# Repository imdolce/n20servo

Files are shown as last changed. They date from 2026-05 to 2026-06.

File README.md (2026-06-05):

<div align="center">
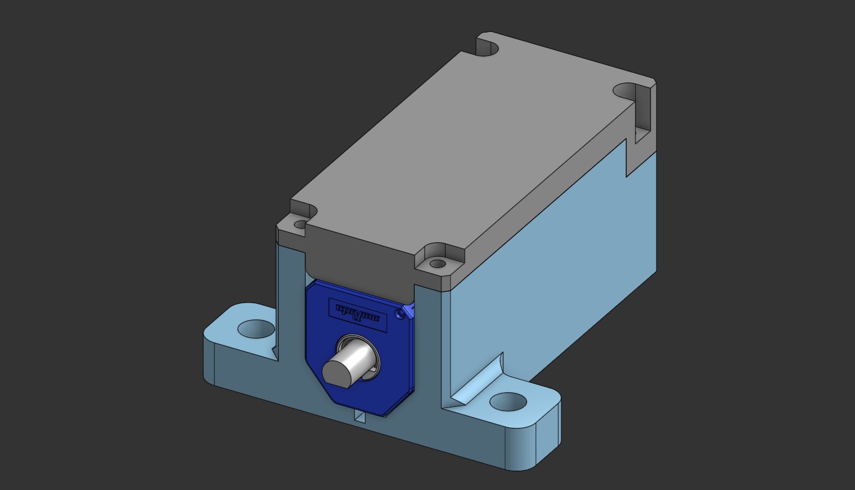
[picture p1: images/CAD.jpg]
N20 Servo CAD Assembly
  
  <h1>N20 Servo</h1>
  <p><strong>A CH32V003-powered small size closed-loop actuator</strong></p>
  
  <p>
    
    
    
    
  </p>
</div>

<hr />

<h2>Table of Contents</h2>
<ul>
  <li><a href="#introduction">1. Introduction</a></li>
  <li><a href="#credits">2. Credits</a></li>
  <li><a href="#technical-specs">3. Technical Specifications</a></li>
  <li><a href="#pcb-and-hardware-revisions">4. PCB & Hardware Revisions</a></li>
  <li><a href="#cad-and-mechanical-design">5. CAD & Mechanical Design</a></li>
  <li><a href="#firmware-and-platformio-environments">6. Firmware & PlatformIO Environments</a></li>
  <li><a href="#additional-tools">7. Additional Tools</a></li>
  <li><a href="#changelog">8. Changelog</a></li>
</ul>

<hr />

<h2 id="introduction">1. Introduction</h2>
<p>
  The <strong>N20 Servo</strong> is an affordable, high-performance(?) closed-loop actuator system built around the WCH CH32V003 RISC-V 32-bit microcontroller. The project was created from my dissatisfaction of the SG90 servo performance: lots of backlash and weak torque, and the failed attempt when trying and modify the servo with the DIY solution (link in Credits) but found it rather hard to properly install the very thin metal wiper and secure the potentiometer body onto the metal surface of the motor. Therefore, I set my goal on creating a better alternative.
</p>
<p>
  This project contains the firmware, CAD assemblies, PCB views, and debugging utilities required to build, test, and tune.
  <br>
  If there's anything wrong, you can raise an issue and let me know. Thank you for your help.
</p>

<hr />

<h2 id="credits">2. Credits</h2>
<p>
  This project is designed, developed, and maintained by: imdolce (aka dolce_st, hovietkien49).
</p>

> [!IMPORTANT]
> Code base development is assisted by OpenAI Codex. On my side, I try to read and comprehend the functions used on this chip or the whole CH32 family in general, as it is my first time working with this chip.

<p>
  Other sources and ideas:
</p>
<ul>
<li>DIY Servo Modding Guide: <a href="https://www.youtube.com/watch?v=6JWuUFiOJBk">How to convert an N20 gear motor into a servo using SG90 parts</a> — by JANIUL HAQ</li>

<li>Angle Sensor Adapter: <a href="https://github.com/jkugalde/N20-Servo-Module">N20-Servo-Module (3D print + N20 motor + angle sensor = servo motor)</a> — by jkugalde</li>

<li>N20 DC Motor CAD Model: <a href="https://grabcad.com/library/n20-dc-gear-motor-1">N20 DC Gear Motor | GrabCAD Library</a> — by RamBros 3D</li>

<li>SG90 CAD Model: <a href="https://grabcad.com/library/sg90-micro-servo-9g-tower-pro-1">SG90 Micro Servo 9g | GrabCAD Library</a> — by Mattheus Frasson</li>

</ul>

<hr />

<h2 id="technical-specs">3. Technical Specifications</h2>
<p>The following table outlines the hardware and software specifications of the N20 Servo:</p>

<table border="1" cellpadding="8" cellspacing="0" style="border-collapse: collapse; width: 100%; border-color: #ddd;">
  <thead>
    <tr style="background-color: #f2f2f2;">
      <th align="left">Parameter</th>
      <th align="left">Specification</th>
      <th align="left">Notes</th>
    </tr>
  </thead>
  <tbody>
    <tr>
      <td><strong>Microcontroller</strong></td>
      <td>WCH CH32V003J4M6 (RISC-V 32-bit Core @ 48 MHz)</td>
      <td>Dirt cheap 5 cents MCU.</td>
    </tr>
    <tr>
      <td><strong>Operating voltage</strong></td>
      <td>5V</td>
      <td>Shared power bus with motor driver.</td>
    </tr>
    <tr>
      <td><strong>Actuator</strong></td>
      <td>N20 Geared DC Motor</td>
      <td>High torque, compact size.</td>
    </tr>
    <tr>
      <td><strong>H-bridge chip</strong></td>
      <td>RZ78xx, SA8301, DRV8210, DRV8837</td>
      <td>RZ78xx driver series include: RZ7888, RZ7889, RZ7899. Currently the RZ7888 and SA8301 are used because it's cheap.</td>
    </tr>
    <tr>
      <td><strong>H-Bridge Output</strong></td>
      <td>Dual-PWM control on <code>PC1</code> and <code>PC2</code></td>
      <td>Drives motor direction and speed using TIM2.</td>
    </tr>
    <tr>
      <td><strong>PWM Frequency</strong></td>
      <td>2.0 kHz</td>
      <td>Adjustable via <code>MOTOR_PWM_HZ</code> in config.</td>
    </tr>
    <tr>
      <td><strong>Position Feedback</strong></td>
      <td>SV01A103AEA01R00 10K (or similar clones) angle position detector (Wiper input pin <code>PA2</code>)</td>
      <td>Read via ADC1 Channel 0, 10-bit resolution..</td>
    </tr>
    <tr>
      <td><strong>Traverse range</strong></td>
      <td>Up to 330° (-165° to +165° symmetrical) mechanical travel</td>
      <td>To make the servo safely accomodate within the wiper track of the angle detector, the traverse angle is limited to 320° (-160° to +160° symmetrical).</td>
    </tr>
    <tr>
      <td><strong>Input Signal</strong></td>
      <td>50 Hz RC Servo PWM, <code>PC4</code></td>
      <td>Captured via TIM1 Channel 4 (1000µs to 2000µs, 0° angle at 1500µs).</td>
    </tr>
    <tr>
      <td><strong>Polling rate</strong></td>
      <td>500 Hz (2 ms)</td>
      <td>Position feedback and control loop.</td>
    </tr>
    <tr>
      <td><strong>Telemetry UART</strong></td>
      <td>921600 baud on <code>PD5</code> (UART1 Remap 2 TX)</td>
      <td>CSV telemetry output for live tuning.</td>
    </tr>
  </tbody>
</table>

<hr />

<h2 id="pcb-and-hardware-revisions">4. PCB & Hardware Revisions</h2>

> [!TIP]
> You can view & get the PCB schematic and designs in this repository, or visit my post on OSHWLAB (coming soon).

> [!IMPORTANT]
> It is not recommended to order PCB of the initial version <code>1D2 (1Д2)</code>, as it requires good soldering skill to install components on both sides and wiring up the angle detector with bodge wires. The <code>1D3 (1Д3)</code> version aims to resolve both issues. More details will be added as soon as I can get my hands on the new <code>1Д3</code> PCB. 

<h3> 1. Initial version  <code>1D2 (1Д2)</code></h3>
<p>The electronics are designed to fit directly on top of the N20 motor. The enclosure is designed specifically for the first revision <code>1Д2</code> </p>

<table border="1" cellpadding="8" cellspacing="0" style="border-collapse: collapse; width: 100%; border-color: #ddd;">
  <thead>
    <tr style="background-color: #f2f2f2;">
      <th align="left" style="width: 25%;">View</th>
      <th align="center" style="width: 45%;">Imagew</th>
      <th align="left" style="width: 30%;">Description</th>
    </tr>
  </thead>
  <tbody>
    <tr>
      <td><strong>PCB View</strong></td>
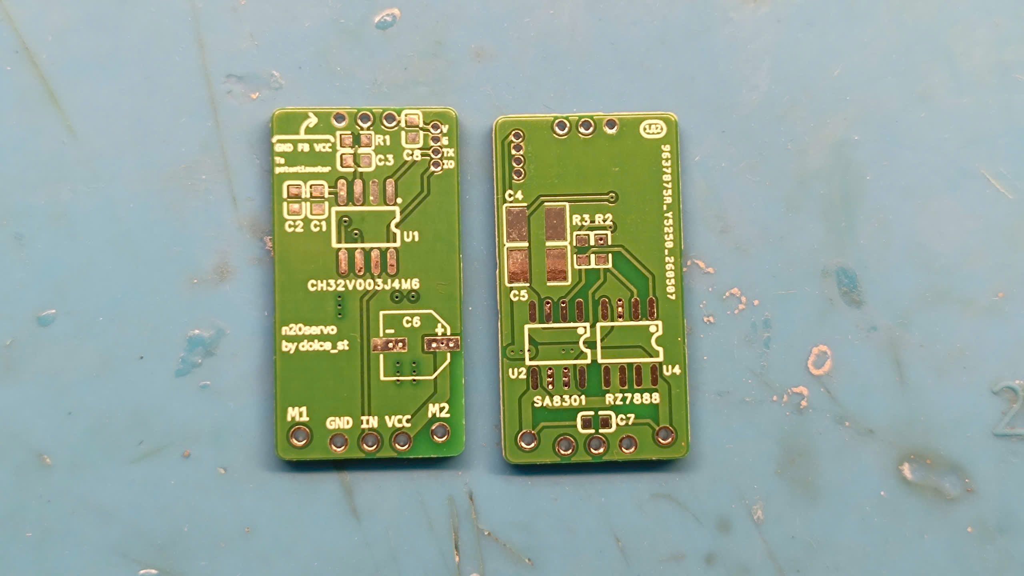
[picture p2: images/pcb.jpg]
      <td align="center"></td>
      <td>Bare PCB appearance, top and bottom view.</td>
    </tr>
    <tr>
      <td><strong>Top populated view</strong></td>
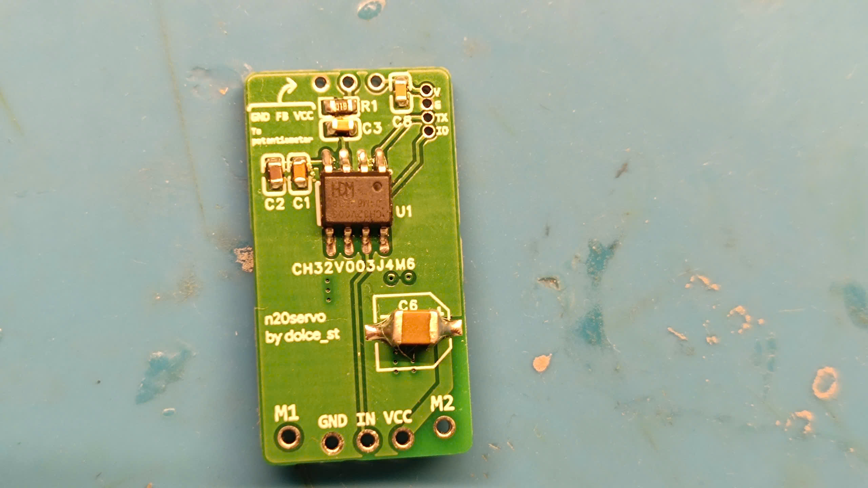
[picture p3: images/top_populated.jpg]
Top Populated PCB
      <td align="center"></td>
      <td>Fully populated top view of the PCB.</td>
    </tr>
    <tr>
      <td><strong>Bottom populated view</strong></td>
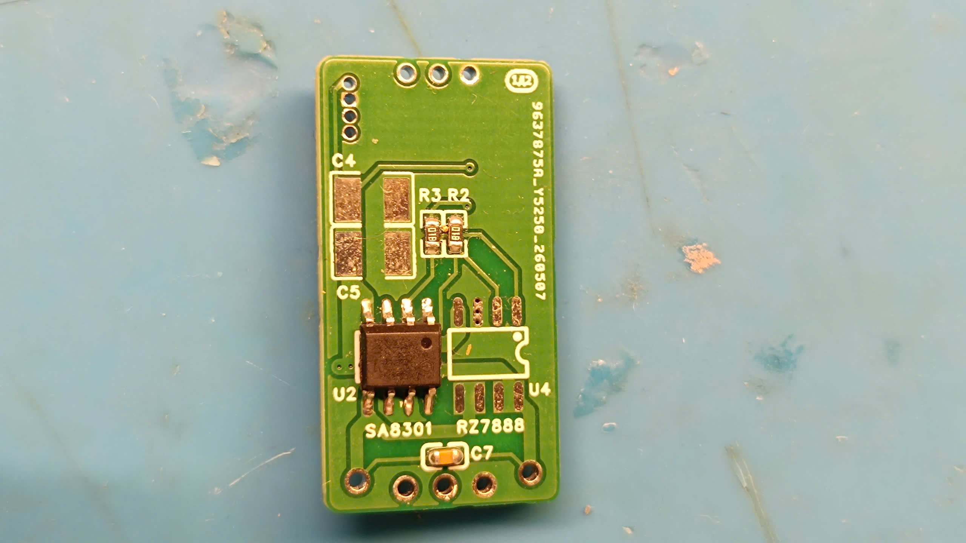
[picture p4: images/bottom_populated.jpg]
Bottom Populated PCB
      <td align="center"></td>
      <td>Partially populated bottom view of the PCB, bottom 2 22uF capacitors are removed due to their interference with the motor below. </td>
    </tr>
    <tr>
      <td><strong>Angle sensor and adapter collet</strong></td>
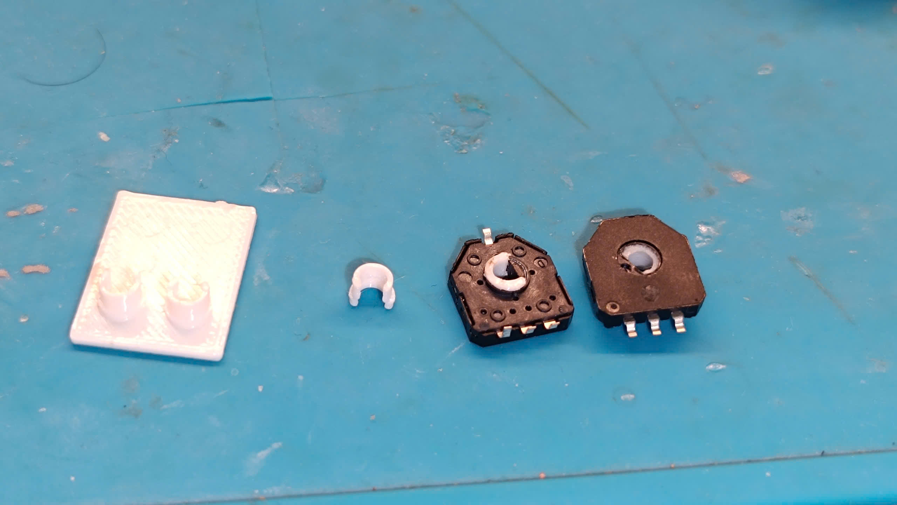
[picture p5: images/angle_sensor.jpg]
Angle Sensor
      <td align="center"></td>
      <td>Top and bottom view of the angle sensor, with the adapter collet installed, the standalone collet (second to the left side) the 3D printed custom fixture to easily print the adapter collets (white rectangle on the left side)</td>
    </tr>
    <tr>
      <td><strong>Test setup</strong></td>
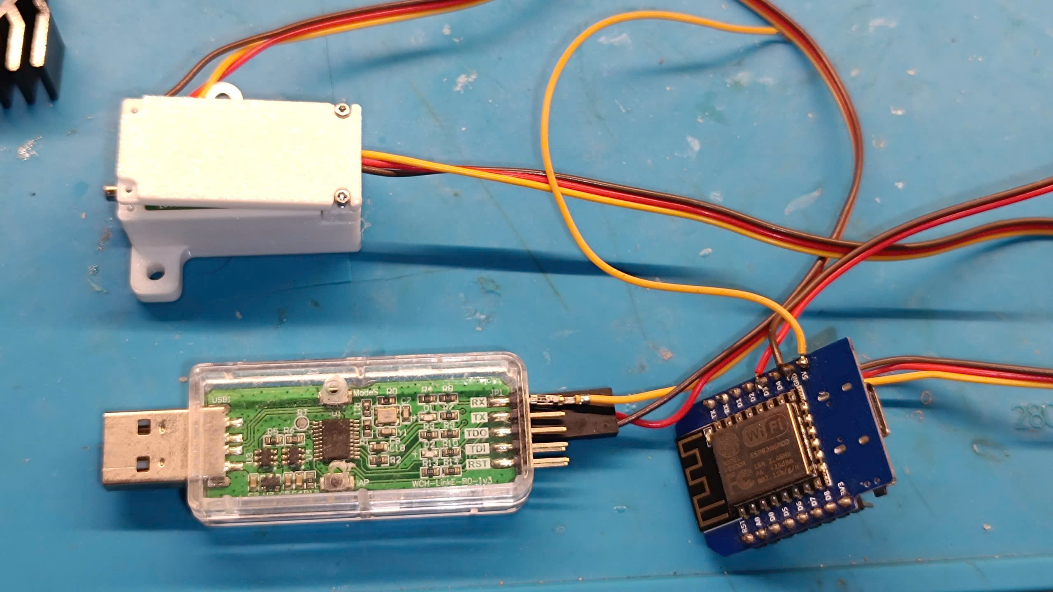
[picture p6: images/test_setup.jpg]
Test Setup
      <td align="center"></td>
      <td>Consists of: Partially assembled N20 Servo assembly (to make space for the Outcoming UART TX telemetry), WEMOS D1 Mini for PWM output, WCH-LinkE for UART telemtry reading and MCU programming.</td>
    </tr>
  </tbody>
</table>

<h3> 2. Second version  <code>1D3 (1Д3)</code></h3>
<p> In this new version, it aims to resolve the difficulty of populating the PCB and wiring the angle detector. Currently I have not tested the design myself, so documentation is limited. There are 5 different PCB designs, <code>1Д3-1/2/3/4</code> incorporates 4 different designs of 4 different motor drivers, it was made to avoid ordering multiple PCB revisions. The remaining 4 designs <code>1Д3-1</code>, <code>1Д3-2</code>, <code>1Д3-3</code>, <code>1Д3-4</code> are standalone boards, using the <code>SA8301</code>, <code>RZ7888</code>, <code>DRV8210DRLR</code>, <code>DRV8837DSGR</code> respectively to each design.</p> 

<table border="1" cellpadding="8" cellspacing="0" style="border-collapse: collapse; width: 100%; border-color: #ddd;">
  <thead>
    <tr style="background-color: #f2f2f2;">
      <th align="left" style="width: 25%;">View</th>
      <th align="center" style="width: 45%;">Image</th>
      <th align="left" style="width: 30%;">Description</th>
    </tr>
  </thead>
  <tbody>
    <tr>
      <td><strong>PCB View</strong></td>
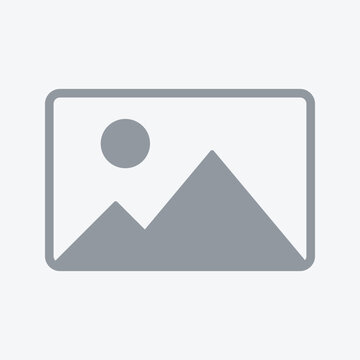
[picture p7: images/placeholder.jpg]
      <td align="center"></td>
      <td>Coming soon.</td>
    </tr>
    <tr>
      <td><strong>Top populated view</strong></td>
      <td align="center">Top Populated PCB</td>
      <td>Coming soon.</td>
    </tr>
    <tr>
      <td><strong>Bottom populated view</strong></td>
      <td align="center">Bottom Populated PCB</td>
      <td>Coming soon.</td>
    </tr>
  </tbody>
</table>

<hr />

<h2 id="cad-and-mechanical-design">5. CAD & Mechanical Design</h2>
<p>
  The enclosure is designed using Onshape. The link is included here: <a href="https://cad.onshape.com/documents/3d875b828e8759d6e6ceaa1a/w/557cd3ef9bc182fa57785d1d/e/bd1feb28422a2b0780a86111">CAD Design </a>
</p>

> [!IMPORTANT]
> Use 4x M1.4x6 Self-tap SHCS and a 1.3mm Allen key or T4 Torx screwdriver bit to close and secure the top cover. The same screw size will persist across all future releases.

<div align="center">
  <table border="0" cellpadding="4" cellspacing="0" style="border-collapse: collapse; margin: auto;">
    <tr>
      <td align="center" style="padding: 10px;">
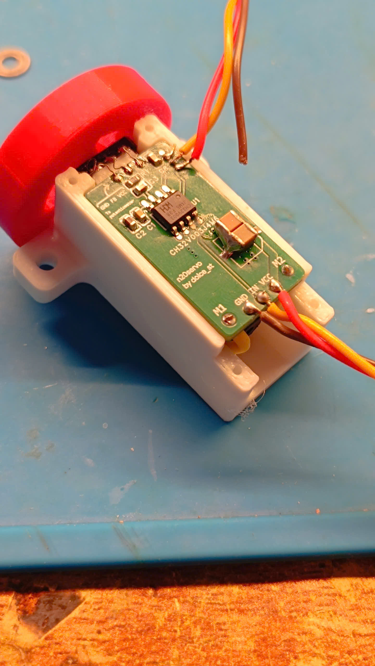
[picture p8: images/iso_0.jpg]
Isometric View
        <br/>
        <em>Isometric View</em>
      </td>
      <td align="center" style="padding: 10px;">
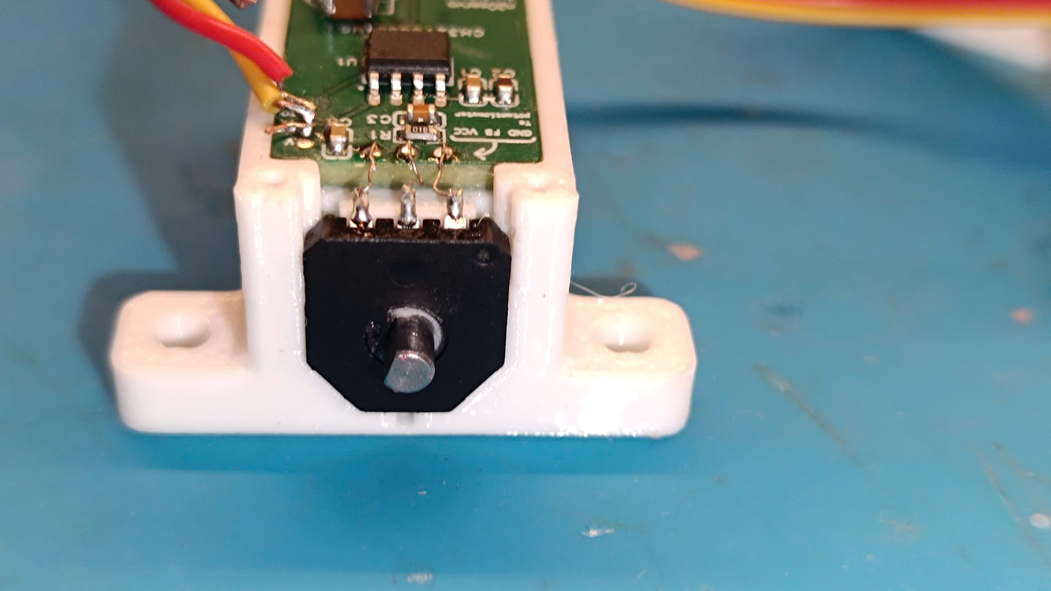
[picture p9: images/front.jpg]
Front View
        <br/>
        <em>Front View</em>
      </td>
    </tr>
    <tr>
      <td align="center" style="padding: 10px;">
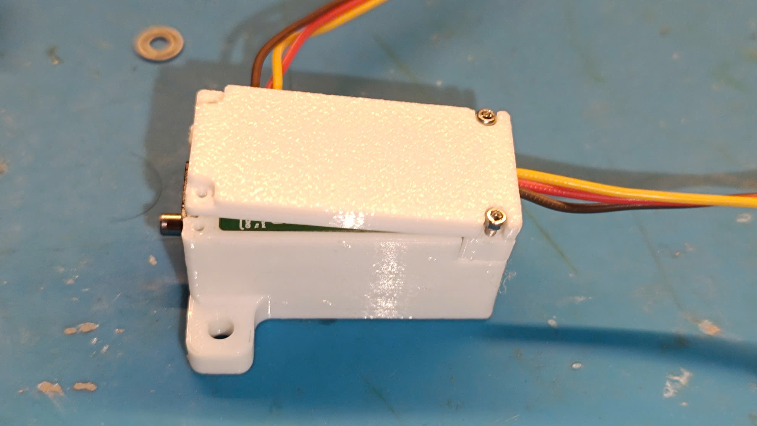
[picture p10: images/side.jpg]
Side View
        <br/>
        <em>Side View</em>
      </td>
      <td align="center" style="padding: 10px;">
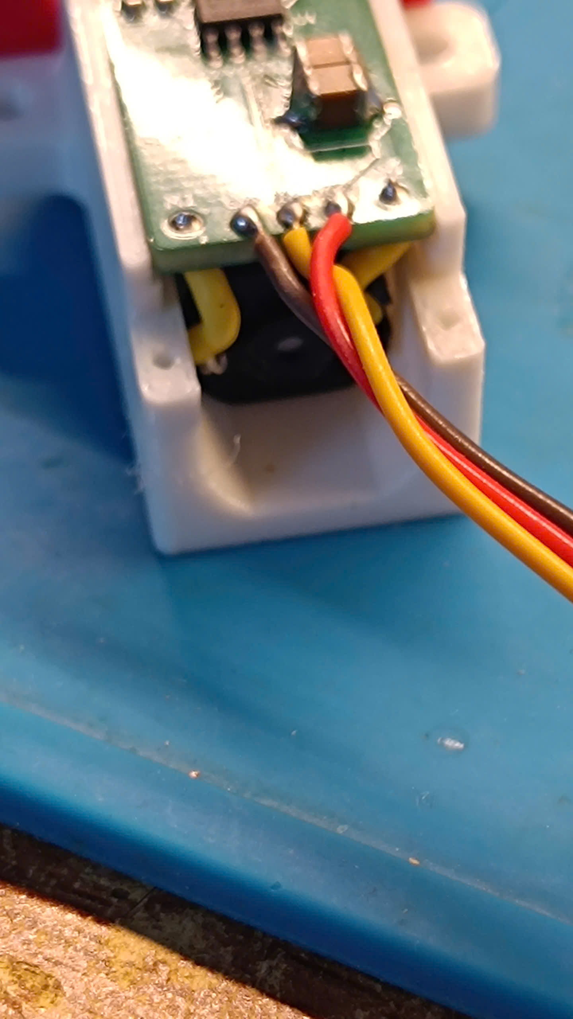
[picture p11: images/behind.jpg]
Rear View
        <br/>
        <em>Rear View</em>
      </td>
    </tr>
    <tr>
      <td align="center" colspan="2" style="padding: 10px;">
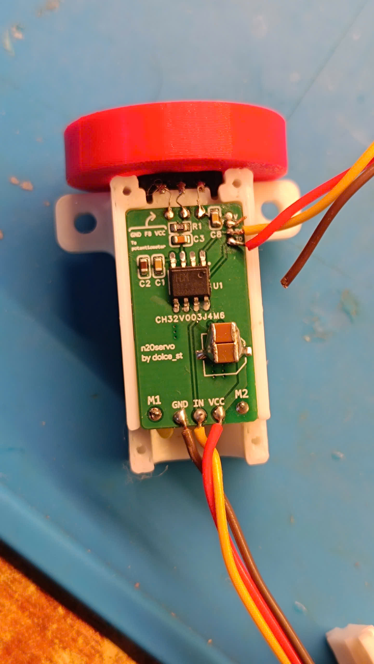
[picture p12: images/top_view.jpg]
Top View
        <br/>
        <em>Top Down View</em>
      </td>
    </tr>
  </table>
</div>

<hr />

<h2 id="firmware-and-platformio-environments">6. Firmware & PlatformIO Environments</h2>
<p>
  The firmware is written in C, using WCH Standard Peripheral Library (StdPeriphLib) <code>aka noneos-sdk</code>. The project is managed using <a href="https://platformio.org/">PlatformIO</a>.
</p>

<h3>Build & Uploading</h3>
<p>To compile and upload the default firmware environment using a WCH-LinkE programmer, run:</p>
<pre><code>platformio run -e genericCH32V003J4M6_servo_control -t upload</code></pre>
<p>Or click the Upload button</p>

<h3>PlatformIO Environments</h3>
<p>The environment for this project is defined in <code>platformio.ini</code>:</p>

<table border="1" cellpadding="8" cellspacing="0" style="border-collapse: collapse; width: 100%; border-color: #ddd;">
  <thead>
    <tr style="background-color: #f2f2f2;">
      <th align="left">Environment Name</th>
      <th align="left">Description</th>
      <th align="left">Build Configurations</th>
    </tr>
  </thead>
  <tbody>
    <tr>
      <td><code>genericCH32V003J4M6_servo_control</code></td>
      <td><strong>Production Closed-Loop Servo</strong>: Primary operational environment. Telemetry output is disabled to prevent UART TX blocks and ensure minimum control loop jitter.</td>
      <td><code>TEST_MODE_SERVO_CONTROL</code><br/><code>SERVO_CONTROL_TELEMETRY_ENABLE=0</code></td>
    </tr>
    <tr>
      <td><code>genericCH32V003J4M6_servo_control_debug</code></td>
      <td><strong>Debug Closed-Loop Servo</strong>: Enables high-speed CSV telemetry output via UART for visualization and tuning.</td>
      <td><code>TEST_MODE_SERVO_CONTROL</code><br/><code>SERVO_CONTROL_TELEMETRY_ENABLE=1</code></td>
    </tr>
    <tr>
      <td><code>genericCH32V003J4M6</code></td>
      <td><strong>Motor Sweep Test</strong>: Periodically drives the motor from limit to limit. Useful for verifying gear engagement, mechanical tolerances, and limits.</td>
      <td><code>TEST_MODE_MOTOR_SWEEP</code></td>
    </tr>
    <tr>
      <td><code>genericCH32V003J4M6_adc_only</code></td>
      <td><strong>ADC Calibrator</strong>: Reads the position potentiometer raw values and displays computed angles. Essential for finding <code>POT_ADC_AT_NEG160</code> and <code>POT_ADC_AT_POS160</code> parameters.</td>
      <td><code>TEST_MODE_ADC_ONLY</code></td>
    </tr>
    <tr>
      <td><code>genericCH32V003J4M6_rc_input_capture</code></td>
      <td><strong>PWM Signal Capture Monitor</strong>: Measures the pulse width and period of incoming RC PWM signals without driving the motor. Used for verifying receiver compatibility.</td>
      <td><code>TEST_MODE_RC_INPUT_CAPTURE</code></td>
    </tr>
  </tbody>
</table>

<hr />

<h2 id="additional-tools">7. Additional Tools</h2>
<p>
  To facilitate tuning and development, the project includes desktop tools located in the <code>tools/</code> folder. Precompiled executables are included alongside their source Python implementations.
  Refer to <a href="tools/README.md">Tools guide</a>
</p>

<h3>1. Serial Dashboard</h3>
<ul>
  <li><strong>File:</strong> <code>tools/python/serial_dashboard.py</code> (Executable: <code>tools/serial_dashboard.exe</code>)</li>
  <li><strong>Description:</strong> Reads the high-speed UART telemetry stream and plots real-time curves showing command target vs. measured position, error metrics, motor duty cycle, and signal validity.</li>
  <li><strong>Usage:</strong>
    <pre><code>python tools/python/serial_dashboard.py --port COM5 --baud 921600</code></pre>
  </li>
  <li><strong>Test / Demo Modes:</strong>
    (This will be removed in the next release).
    <pre><code>python tools/python/serial_dashboard.py --demo --demo-mode servo
python tools/python/serial_dashboard.py --self-test</code></pre>
    Or use the included executeable.
  </li>
</ul>

<h3>2. Servo Configurator</h3>
<ul>
  <li><strong>File:</strong> <code>tools/python/servo_configurator.py</code> (Executable: <code>tools/servo_configurator.exe</code>)</li>
  <li><strong>Description:</strong> A graphical user interface using Tkinter for inspecting and editing the configuration header <code>include/servo_config.h</code>. It automatically checks configuration boundaries, performs self-tests, and saves a timestamped backup before modifying the file.</li>
  <li><strong>Usage:</strong>
    <pre><code>python tools/python/servo_configurator.py</code></pre>
    Or use the included executeable.
  </li>
</ul>

<hr />

<h2 id="changelog">8. Changelog</h2>
<ul>
  <li><strong>v1.1.0</strong>: Added precompiled executable for <code>serial_dashboard.py</code> and <code>servo_configurator.py</code>, released new PCB version <code>1Д3-1/2/3/4</code> and its standalone variants.</li>
  <li><strong>v1.0.0</strong>: Initial release, no documentation available..</li>
</ul>

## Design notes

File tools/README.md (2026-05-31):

# Serial Dashboard

Run the dashboard against the CH32V003 UART CSV output:

```powershell
python tools\serial_dashboard.py --port COM5 --baud 921600
```

Use the COM port shown by your USB-UART adapter. Close PlatformIO's serial
monitor before connecting, because only one program can normally hold the COM
port at a time.

The default `genericCH32V003J4M6_servo_control` firmware disables servo-control
telemetry so UART TX cannot block the control loop. Build
`genericCH32V003J4M6_servo_control_debug` when you want dashboard output:

```powershell
platformio run -e genericCH32V003J4M6_servo_control_debug -t upload
```

The dashboard auto-detects both firmware output modes:

- ADC / motor sweep:
  `sample,raw,avg16,mv,pct,angle_deg,direction_changes`
- RC input capture:
  `frame,pulse_us,period_us,freq_hz,valid,sg90_deg,n20_deg`
- Closed-loop servo control:
  `sample,target_deg,angle_deg,error_deg,duty,pulse_us,valid`

Useful test commands:

```powershell
python tools\serial_dashboard.py --demo --demo-mode adc
python tools\serial_dashboard.py --demo --demo-mode rc
python tools\serial_dashboard.py --demo --demo-mode servo
python tools\serial_dashboard.py --self-test
```

If `pyserial` is missing:

```powershell
python -m pip install -r requirements-dashboard.txt
```

## Servo Configurator

Run the Tkinter configurator for `include/servo_config.h`:

```powershell
python tools\servo_configurator.py
```

It edits the existing `#define` values, validates common range mistakes, and
creates a timestamped `.bak` copy of the header every time you save.

Parser/validation check without opening the GUI:

```powershell
python tools\servo_configurator.py --self-test
```

Changing `TEST_MODE` or `SERVO_CONTROL_TELEMETRY_ENABLE` in the header only
affects builds where `platformio.ini` does not override those macros with
`build_flags`.

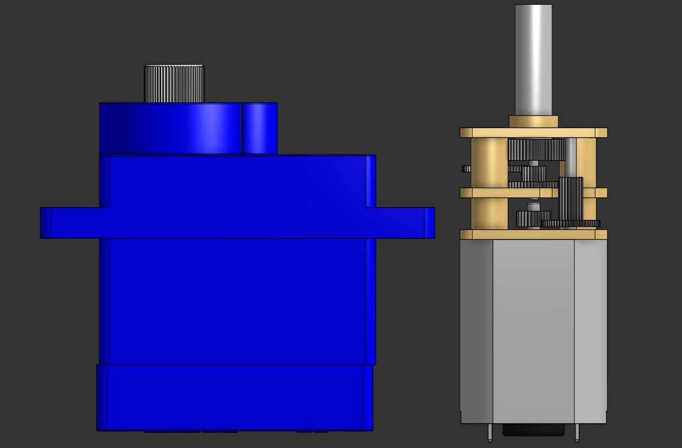
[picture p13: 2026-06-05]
images/compare.jpg

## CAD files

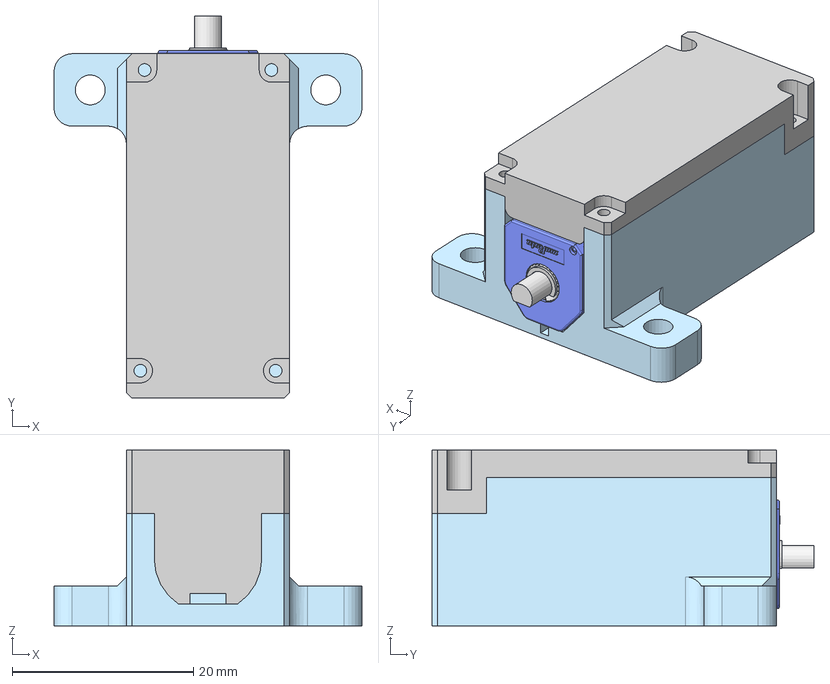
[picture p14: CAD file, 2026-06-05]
cad/Servo Assembly.step
34.0 x 42.2 x 19.4 mm
Gear Box x 8
SV01A???
v1
Shaft
?2-2 Top cover
Board~6sVb
Motor
?2-1 Body

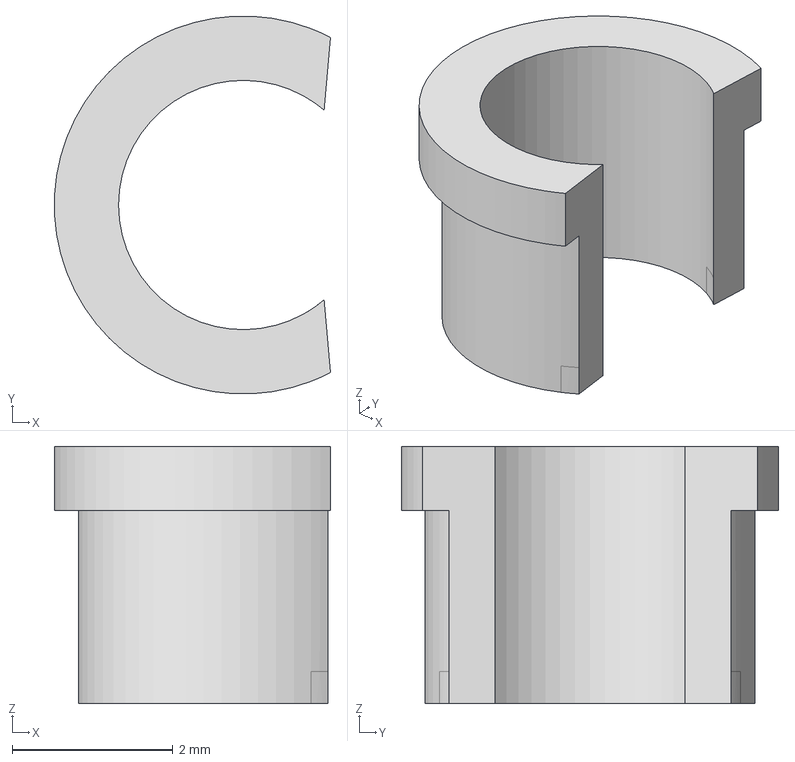
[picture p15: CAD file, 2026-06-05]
cad/Adapter collet.step
3.43 x 4.69 x 3.20 mm

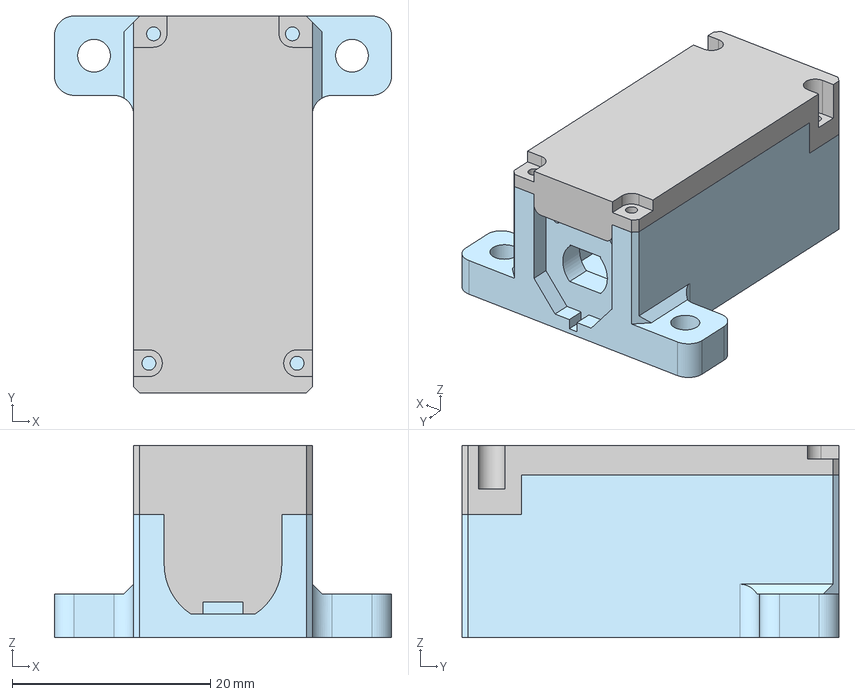
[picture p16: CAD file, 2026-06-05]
cad/Body and cover (Д2).step
34.0 x 38.0 x 19.4 mm

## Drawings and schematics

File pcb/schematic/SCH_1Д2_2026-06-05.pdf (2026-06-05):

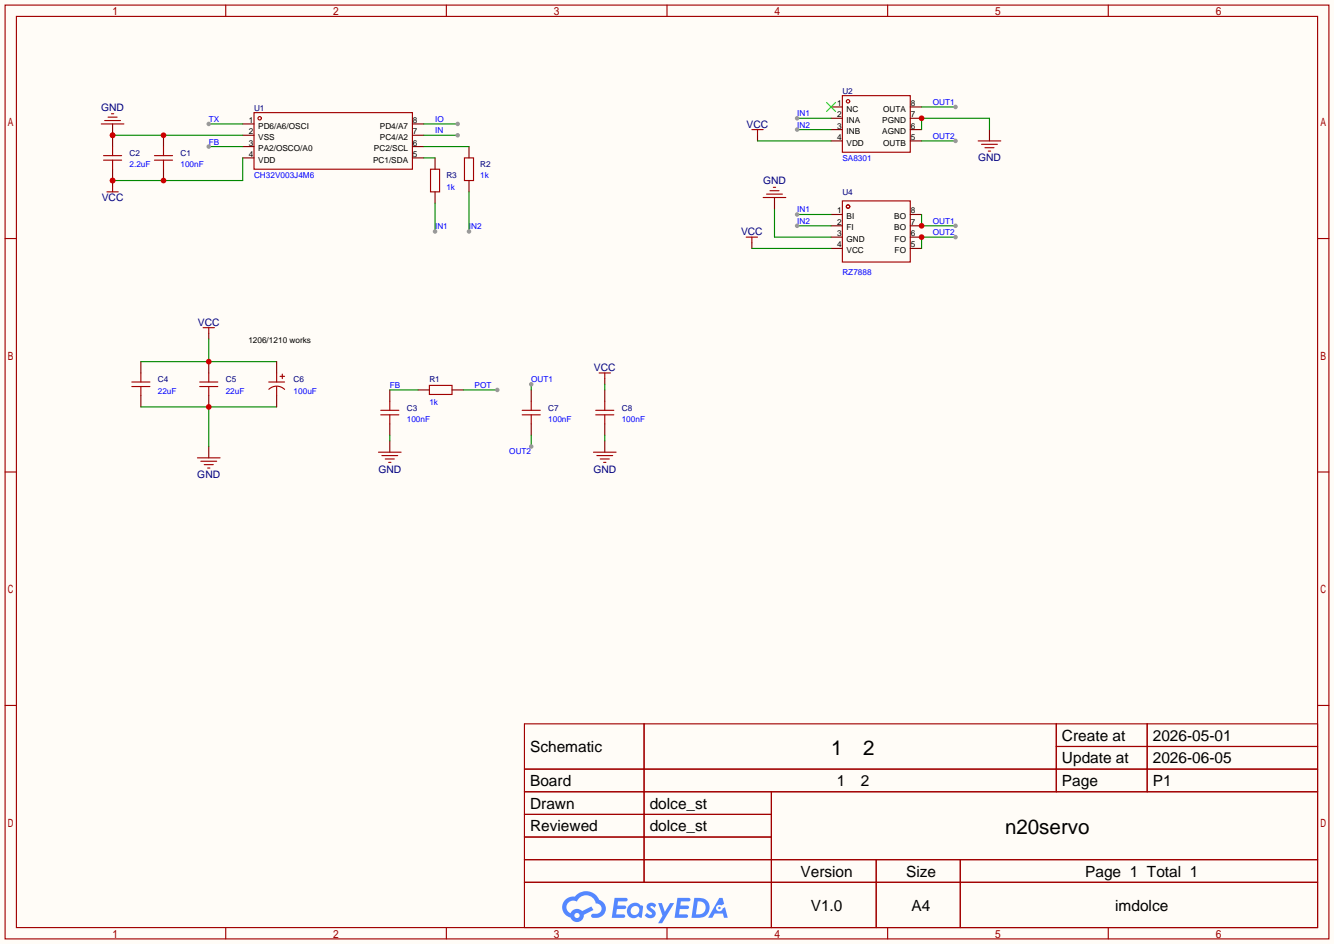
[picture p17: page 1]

Schematic | 1 2 | Create at | 2026-05-01

Update at | 2026-06-05

Board | 1 2 | Page | P1
Drawn | dolce_st | n20servo
Reviewed | dolce_st

Version | Size | Page 1 Total 1
V1.0 | A4 | imdolce

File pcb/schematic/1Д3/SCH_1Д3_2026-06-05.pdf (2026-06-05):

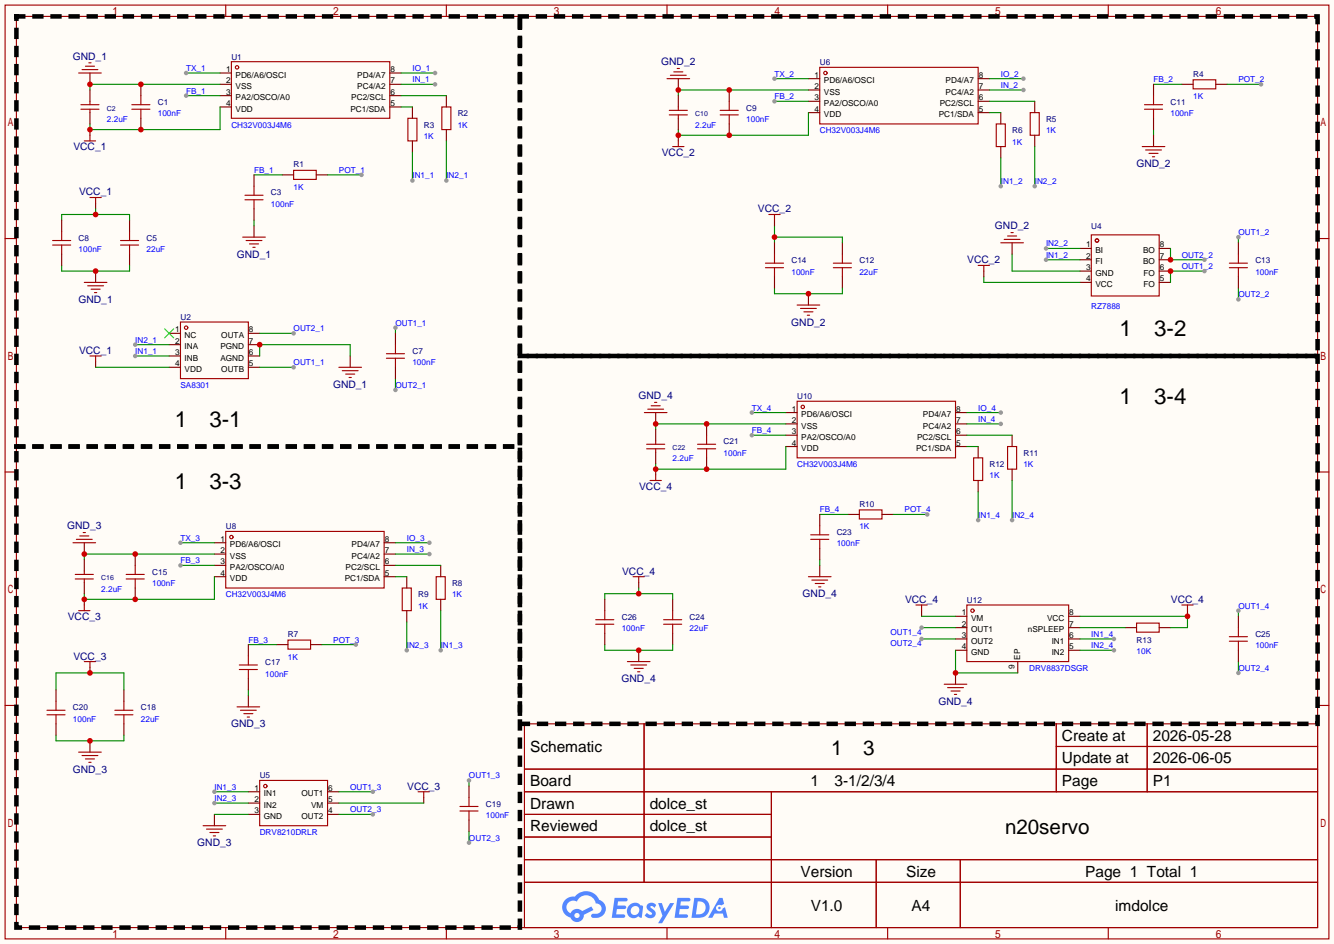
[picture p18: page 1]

Schematic | 1 3 | Create at | 2026-05-28

Update at | 2026-06-05

Board | 1 3-1/2/3/4 | Page | P1
Drawn | dolce_st | n20servo
Reviewed | dolce_st

Version | Size | Page 1 Total 1
V1.0 | A4 | imdolce

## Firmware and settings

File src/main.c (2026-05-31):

#include <ch32v00x.h>
#include <debug.h>

#include "servo_config.h"

#define MODE_USES_ADC                                                          \
  ((TEST_MODE == TEST_MODE_ADC_ONLY) ||                                        \
   (TEST_MODE == TEST_MODE_MOTOR_SWEEP) ||                                     \
   (TEST_MODE == TEST_MODE_SERVO_CONTROL))
#define MODE_USES_MOTOR                                                        \
  ((TEST_MODE == TEST_MODE_MOTOR_SWEEP) ||                                     \
   (TEST_MODE == TEST_MODE_SERVO_CONTROL))
#define MODE_USES_RC_INPUT                                                     \
  ((TEST_MODE == TEST_MODE_RC_INPUT_CAPTURE) ||                                \
   (TEST_MODE == TEST_MODE_SERVO_CONTROL))
#define MODE_USES_PRINTF                                                       \
  ((TEST_MODE != TEST_MODE_SERVO_CONTROL) ||                                   \
   (SERVO_CONTROL_TELEMETRY_ENABLE != 0))
#define MODE_USES_SAMPLE_INDEX                                                 \
  ((TEST_MODE == TEST_MODE_ADC_ONLY) ||                                        \
   (TEST_MODE == TEST_MODE_MOTOR_SWEEP) ||                                     \
   ((TEST_MODE == TEST_MODE_SERVO_CONTROL) &&                                  \
    (SERVO_CONTROL_TELEMETRY_ENABLE != 0)))

typedef enum { SWEEP_TOWARD_LOW = 0, SWEEP_TOWARD_HIGH = 1 } SweepDirection;

typedef enum {
  MOTOR_PWM_COMMAND_COAST = 0,
  MOTOR_PWM_COMMAND_BRAKE = 1,
  MOTOR_PWM_COMMAND_TOWARD_HIGH = 2,
  MOTOR_PWM_COMMAND_TOWARD_LOW = 3,
} MotorPwmCommand;

void NMI_Handler(void) __attribute__((interrupt("WCH-Interrupt-fast")));
void HardFault_Handler(void) __attribute__((interrupt("WCH-Interrupt-fast")));
#if MODE_USES_RC_INPUT
void TIM1_CC_IRQHandler(void) __attribute__((interrupt("WCH-Interrupt-fast")));
#endif
#if MODE_USES_MOTOR
void TIM2_IRQHandler(void) __attribute__((interrupt("WCH-Interrupt-fast")));
#endif

#if MODE_USES_RC_INPUT
static uint16_t timer_delta_u16(uint16_t newer, uint16_t older) {
  return (uint16_t)(newer - older);
}

static uint16_t clamp_u16(uint16_t value, uint16_t low, uint16_t high) {
  if (value < low) {
    return low;
  }

  if (value > high) {
    return high;
  }

  return value;
}

static uint32_t abs_i32_to_u32(int32_t value) {
  return value < 0 ? (uint32_t)(-value) : (uint32_t)value;
}
#endif

#if TEST_MODE == TEST_MODE_SERVO_CONTROL
static int32_t clamp_i32(int32_t value, int32_t low, int32_t high) {
  if (value < low) {
    return low;
  }

  if (value > high) {
    return high;
  }

  return value;
}
#endif

#if MODE_USES_RC_INPUT
static volatile uint16_t rc_last_rising_capture_us = 0;
static volatile uint16_t rc_pulse_width_us = 0;
static volatile uint16_t rc_period_us = 0;
static volatile uint32_t rc_frame_count = 0;
static volatile uint8_t rc_have_rising_edge = 0;
static volatile uint8_t rc_waiting_for_falling_edge = 0;

static uint16_t clamp_pulse_us(uint16_t pulse_us) {
  return clamp_u16(pulse_us, RC_INPUT_MIN_US, RC_INPUT_MAX_US);
}

static int32_t rc_pulse_to_signed_angle_tenths(uint16_t pulse_us,
                                               int32_t full_scale_tenths) {
  int32_t clamped_pulse = (int32_t)clamp_pulse_us(pulse_us);
  return ((clamped_pulse - (int32_t)RC_INPUT_CENTER_US) * full_scale_tenths) /
         ((int32_t)RC_INPUT_MAX_US - (int32_t)RC_INPUT_CENTER_US);
}

static uint8_t rc_capture_is_valid(uint16_t pulse_us, uint16_t period_us) {
  return pulse_us >= RC_INPUT_VALID_MIN_US &&
         pulse_us <= RC_INPUT_VALID_MAX_US &&
         period_us >= RC_INPUT_PERIOD_VALID_MIN_US &&
         period_us <= RC_INPUT_PERIOD_VALID_MAX_US;
}

static void rc_capture_snapshot(uint32_t *frame_count, uint16_t *pulse_us,
                                uint16_t *period_us) {
  __disable_irq();
  *frame_count = rc_frame_count;
  *pulse_us = rc_pulse_width_us;
  *period_us = rc_period_us;
  __enable_irq();
}

static void rc_input_capture_init_pc4(void) {
  GPIO_InitTypeDef GPIO_InitStructure = {0};
  TIM_TimeBaseInitTypeDef TIM_TimeBaseStructure = {0};
  TIM_ICInitTypeDef TIM_ICInitStructure = {0};

  RCC_APB2PeriphClockCmd(
      RCC_APB2Periph_GPIOC | RCC_APB2Periph_AFIO | RCC_APB2Periph_TIM1, ENABLE);

  GPIO_PinRemapConfig(GPIO_PartialRemap2_TIM1, ENABLE);

  GPIO_InitStructure.GPIO_Pin = RC_INPUT_GPIO_PIN;
  GPIO_InitStructure.GPIO_Mode = GPIO_Mode_IN_FLOATING;
  GPIO_Init(RC_INPUT_GPIO_PORT, &GPIO_InitStructure);

  TIM_DeInit(TIM1);
  TIM_TimeBaseStructure.TIM_Period = 0xFFFF;
  TIM_TimeBaseStructure.TIM_Prescaler =
      (uint16_t)((SystemCoreClock / 1000000U) - 1U);
  TIM_TimeBaseStructure.TIM_ClockDivision = TIM_CKD_DIV1;
  TIM_TimeBaseStructure.TIM_CounterMode = TIM_CounterMode_Up;
  TIM_TimeBaseInit(TIM1, &TIM_TimeBaseStructure);

  TIM_ICInitStructure.TIM_Channel = TIM_Channel_4;
  TIM_ICInitStructure.TIM_ICPolarity = TIM_ICPolarity_Rising;
  TIM_ICInitStructure.TIM_ICSelection = TIM_ICSelection_DirectTI;
  TIM_ICInitStructure.TIM_ICPrescaler = TIM_ICPSC_DIV1;
  TIM_ICInitStructure.TIM_ICFilter = 0x03;
  TIM_ICInit(TIM1, &TIM_ICInitStructure);

  TIM_ClearITPendingBit(TIM1, TIM_IT_CC4);
  TIM_ITConfig(TIM1, TIM_IT_CC4, ENABLE);
  NVIC_EnableIRQ(TIM1_CC_IRQn);
  TIM_Cmd(TIM1, ENABLE);
  __enable_irq();
}
#endif

#if MODE_USES_ADC
static void adc_init_pa2_a0(void) {
  GPIO_InitTypeDef GPIO_InitStructure = {0};
  ADC_InitTypeDef ADC_InitStructure = {0};

  RCC_APB2PeriphClockCmd(RCC_APB2Periph_GPIOA | RCC_APB2Periph_ADC1, ENABLE);
  RCC_ADCCLKConfig(RCC_PCLK2_Div8);

  GPIO_InitStructure.GPIO_Pin = ADC_INPUT_GPIO_PIN;
  GPIO_InitStructure.GPIO_Mode = GPIO_Mode_AIN;
  GPIO_Init(ADC_INPUT_GPIO_PORT, &GPIO_InitStructure);

  ADC_DeInit(ADC1);
  ADC_InitStructure.ADC_Mode = ADC_Mode_Independent;
  ADC_InitStructure.ADC_ScanConvMode = DISABLE;
  ADC_InitStructure.ADC_ContinuousConvMode = DISABLE;
  ADC_InitStructure.ADC_ExternalTrigConv = ADC_ExternalTrigConv_None;
  ADC_InitStructure.ADC_DataAlign = ADC_DataAlign_Right;
  ADC_InitStructure.ADC_NbrOfChannel = 1;
  ADC_Init(ADC1, &ADC_InitStructure);

  ADC_RegularChannelConfig(ADC1, ADC_INPUT_CHANNEL, 1,
                           ADC_SampleTime_241Cycles);
  ADC_Cmd(ADC1, ENABLE);

  ADC_ResetCalibration(ADC1);
  while (ADC_GetResetCalibrationStatus(ADC1) == SET) {
  }

  ADC_StartCalibration(ADC1);
  while (ADC_GetCalibrationStatus(ADC1) == SET) {
  }
}

static uint16_t adc_read_raw(void) {
  ADC_ClearFlag(ADC1, ADC_FLAG_EOC);
  ADC_SoftwareStartConvCmd(ADC1, ENABLE);

  while (ADC_GetFlagStatus(ADC1, ADC_FLAG_EOC) == RESET) {
  }

  return ADC_GetConversionValue(ADC1) & ADC_FULL_SCALE_COUNTS;
}

static uint16_t adc_read_average(uint8_t samples) {
  uint32_t sum = 0;

  for (uint8_t i = 0; i < samples; i++) {
    sum += adc_read_raw();
  }

  return (uint16_t)((sum + (samples / 2U)) / samples);
}

#if TEST_MODE != TEST_MODE_SERVO_CONTROL
static uint32_t adc_to_pot_angle_tenths(uint16_t adc_count) {
  return ((uint32_t)adc_count * ANGLE_FULL_SCALE_DEGREES * 10U +
          (ADC_FULL_SCALE_COUNTS / 2U)) /
         ADC_FULL_SCALE_COUNTS;
}
#endif

#if TEST_MODE == TEST_MODE_SERVO_CONTROL
static int32_t adc_to_servo_angle_tenths(uint16_t adc_count) {
  int32_t adc = (int32_t)adc_count;
  int32_t center = (int32_t)POT_ADC_AT_CENTER;

  if (adc >= center) {
    int32_t span = (int32_t)POT_ADC_AT_POS160 - center;
    int32_t angle =
        ((adc - center) * SERVO_ANGLE_FULL_SCALE_TENTHS + (span / 2)) / span;
    return clamp_i32(angle, 0, SERVO_ANGLE_FULL_SCALE_TENTHS);
  }

  int32_t span = center - (int32_t)POT_ADC_AT_NEG160;
  int32_t angle =
      ((center - adc) * SERVO_ANGLE_FULL_SCALE_TENTHS + (span / 2)) / span;
  return -clamp_i32(angle, 0, SERVO_ANGLE_FULL_SCALE_TENTHS);
}

static int32_t compensate_command_angle_tenths(int32_t command_tenths) {
  int32_t rounding = command_tenths >= 0 ? 500 : -500;
  int32_t compensated =
      ((command_tenths * SERVO_COMMAND_GAIN_PERMILLE) + rounding) / 1000 +
      SERVO_COMMAND_OFFSET_TENTHS;

#if SERVO_ENDPOINT_PROTECTION_ENABLE
  int32_t limit_tenths = (int32_t)SERVO_ENDPOINT_LIMIT_TENTHS;
  limit_tenths =
      clamp_i32(limit_tenths, 0, (int32_t)SERVO_ANGLE_FULL_SCALE_TENTHS);
  return clamp_i32(compensated, -limit_tenths, limit_tenths);
#else
  return clamp_i32(compensated, -SERVO_ANGLE_FULL_SCALE_TENTHS,
                   SERVO_ANGLE_FULL_SCALE_TENTHS);
#endif
}
#endif
#endif

#if MODE_USES_MOTOR
static volatile MotorPwmCommand motor_pwm_command = MOTOR_PWM_COMMAND_COAST;
static volatile uint16_t motor_pwm_duty_ticks = 0;

static uint16_t motor_pwm_duty_to_ticks(uint16_t duty) {
  uint32_t ticks;

  if (duty >= MOTOR_PWM_DUTY_MAX) {
    return MOTOR_PWM_PERIOD_TICKS;
  }

  if (duty == 0U) {
    return 0U;
  }

  ticks =
      ((uint32_t)duty * MOTOR_PWM_PERIOD_TICKS + (MOTOR_PWM_DUTY_MAX / 2U)) /
      MOTOR_PWM_DUTY_MAX;
  if (ticks == 0U) {
    ticks = 1U;
  }

  return (uint16_t)ticks;
}

static void motor_pwm_apply_period_start(MotorPwmCommand command,
                                         uint16_t duty_ticks) {
  if (command == MOTOR_PWM_COMMAND_BRAKE) {
    GPIO_SetBits(MOTOR_GPIO_PORT, MOTOR_GPIO_PINS);
    return;
  }

  GPIO_ResetBits(MOTOR_GPIO_PORT, MOTOR_GPIO_PINS);

  if (duty_ticks == 0U) {
    return;
  }

  if (command == MOTOR_PWM_COMMAND_TOWARD_HIGH) {
    GPIO_SetBits(MOTOR_GPIO_PORT, MOTOR_TOWARD_HIGH_PIN);
  } else if (command == MOTOR_PWM_COMMAND_TOWARD_LOW) {
    GPIO_SetBits(MOTOR_GPIO_PORT, MOTOR_TOWARD_LOW_PIN);
  }
}

static void motor_pwm_init(void) {
  GPIO_InitTypeDef GPIO_InitStructure = {0};
  TIM_TimeBaseInitTypeDef TIM_TimeBaseStructure = {0};
  TIM_OCInitTypeDef TIM_OCInitStructure = {0};

  RCC_APB2PeriphClockCmd(RCC_APB2Periph_GPIOC, ENABLE);
  RCC_APB1PeriphClockCmd(RCC_APB1Periph_TIM2, ENABLE);

  GPIO_InitStructure.GPIO_Pin = MOTOR_GPIO_PINS;
  GPIO_InitStructure.GPIO_Mode = GPIO_Mode_Out_PP;
  GPIO_InitStructure.GPIO_Speed = GPIO_Speed_30MHz;
  GPIO_Init(MOTOR_GPIO_PORT, &GPIO_InitStructure);
  GPIO_ResetBits(MOTOR_GPIO_PORT, MOTOR_GPIO_PINS);

  TIM_DeInit(TIM2);
  TIM_TimeBaseStructure.TIM_Period = (uint16_t)(MOTOR_PWM_PERIOD_TICKS - 1U);
  TIM_TimeBaseStructure.TIM_Prescaler =
      (uint16_t)((SystemCoreClock / MOTOR_PWM_TIMER_HZ) - 1U);
  TIM_TimeBaseStructure.TIM_ClockDivision = TIM_CKD_DIV1;
  TIM_TimeBaseStructure.TIM_CounterMode = TIM_CounterMode_Up;
  TIM_TimeBaseInit(TIM2, &TIM_TimeBaseStructure);

  TIM_OCInitStructure.TIM_OCMode = TIM_OCMode_Timing;
  TIM_OCInitStructure.TIM_OutputState = TIM_OutputState_Disable;
  TIM_OCInitStructure.TIM_Pulse = 0;
  TIM_OCInitStructure.TIM_OCPolarity = TIM_OCPolarity_High;
  TIM_OC1Init(TIM2, &TIM_OCInitStructure);

  TIM_ClearITPendingBit(TIM2, TIM_IT_Update | TIM_IT_CC1);
  TIM_ITConfig(TIM2, TIM_IT_Update | TIM_IT_CC1, ENABLE);
  NVIC_EnableIRQ(TIM2_IRQn);
  TIM_Cmd(TIM2, ENABLE);
  __enable_irq();
}

static void motor_pwm_set(MotorPwmCommand command, uint16_t duty) {
  uint16_t duty_ticks;

  if (command == MOTOR_PWM_COMMAND_COAST) {
    duty = 0U;
  } else if (command == MOTOR_PWM_COMMAND_BRAKE) {
    duty = MOTOR_PWM_DUTY_MAX;
  } else if (duty > MOTOR_PWM_DUTY_MAX) {
    duty = MOTOR_PWM_DUTY_MAX;
  }

  duty_ticks = motor_pwm_duty_to_ticks(duty);

  __disable_irq();
  motor_pwm_duty_ticks = duty_ticks;
  motor_pwm_command = command;
  TIM_SetCompare1(TIM2, duty_ticks);
  motor_pwm_apply_period_start(command, duty_ticks);
  __enable_irq();
}

static void motor_pwm_coast(void) {
  motor_pwm_set(MOTOR_PWM_COMMAND_COAST, 0U);
}

static void motor_pwm_brake(void) {
  motor_pwm_set(MOTOR_PWM_COMMAND_BRAKE, MOTOR_PWM_DUTY_MAX);
}

static void motor_pwm_drive_toward_high(uint16_t duty) {
  motor_pwm_set(MOTOR_PWM_COMMAND_TOWARD_HIGH, duty);
}

static void motor_pwm_drive_toward_low(uint16_t duty) {
  motor_pwm_set(MOTOR_PWM_COMMAND_TOWARD_LOW, duty);
}

#if TEST_MODE == TEST_MODE_SERVO_CONTROL
static uint16_t control_duty_from_error(uint32_t abs_error_tenths) {
  uint32_t duty;

  if (abs_error_tenths <= CONTROL_POSITION_DEADBAND_TENTHS) {
    return 0U;
  }

  if (abs_error_tenths >= CONTROL_SLOW_ZONE_TENTHS) {
    return MOTOR_PWM_DUTY_MAX;
  }

  duty = MOTOR_PWM_MIN_DUTY +
         ((abs_error_tenths - CONTROL_POSITION_DEADBAND_TENTHS) *
          (MOTOR_PWM_DUTY_MAX - MOTOR_PWM_MIN_DUTY)) /
             (CONTROL_SLOW_ZONE_TENTHS - CONTROL_POSITION_DEADBAND_TENTHS);
  return (uint16_t)clamp_u16((uint16_t)duty, MOTOR_PWM_MIN_DUTY,
                             MOTOR_PWM_DUTY_MAX);
}
#endif
#endif

int main(void) {
#if MODE_USES_SAMPLE_INDEX
  uint32_t sample_index = 0;
#endif

#if TEST_MODE == TEST_MODE_MOTOR_SWEEP
  uint32_t direction_changes = 0;
  SweepDirection sweep_direction = SWEEP_TOWARD_LOW;
  uint8_t endpoint_armed = 1;
  uint32_t sweep_midpoint_tenths =
      (SWEEP_LOW_TARGET_TENTHS + SWEEP_HIGH_TARGET_TENTHS) / 2U;
#endif

#if TEST_MODE == TEST_MODE_SERVO_CONTROL
  int32_t target_angle_tenths = 0;
  int8_t last_drive_direction = 0;
  uint32_t last_rc_frame_count = 0;
  uint16_t rc_stale_loops =
      (uint16_t)(RC_INPUT_TIMEOUT_MS / CONTROL_LOOP_INTERVAL_MS);
#if SERVO_CONTROL_TELEMETRY_ENABLE
  uint16_t debug_elapsed_ms = CONTROL_DEBUG_INTERVAL_MS;
#endif
#endif

  SystemCoreClockUpdate();
  Delay_Init();

#if MODE_USES_PRINTF
#if (SDI_PRINT == SDI_PR_OPEN)
  SDI_Printf_Enable();
#else
  USART_Printf_Init(UART_BAUD_RATE);
#endif
#endif

#if MODE_USES_ADC
  adc_init_pa2_a0();
#endif

#if MODE_USES_RC_INPUT
  rc_input_capture_init_pc4();
#endif

#if MODE_USES_MOTOR
  motor_pwm_init();
  motor_pwm_coast();
#endif

#if TEST_MODE == TEST_MODE_RC_INPUT_CAPTURE
  printf("frame,pulse_us,period_us,freq_hz,valid,sg90_deg,n20_deg\r\n");
#elif TEST_MODE == TEST_MODE_SERVO_CONTROL && SERVO_CONTROL_TELEMETRY_ENABLE
  printf("sample,target_deg,angle_deg,error_deg,duty,pulse_us,valid\r\n");
#endif

#if TEST_MODE == TEST_MODE_MOTOR_SWEEP
  uint32_t startup_angle_tenths =
      adc_to_pot_angle_tenths(adc_read_average(ADC_AVERAGE_SAMPLES));
  sweep_direction = (startup_angle_tenths < sweep_midpoint_tenths)
                        ? SWEEP_TOWARD_HIGH
                        : SWEEP_TOWARD_LOW;
#endif

  while (1) {
#if TEST_MODE == TEST_MODE_RC_INPUT_CAPTURE
    uint32_t frame_count;
    uint16_t pulse_us;
    uint16_t period_us;
    uint32_t freq_tenths;
    uint8_t valid;
    int32_t sg90_angle_tenths;
    int32_t n20_angle_tenths;
    uint32_t sg90_abs_tenths;
    uint32_t n20_abs_tenths;

    rc_capture_snapshot(&frame_count, &pulse_us, &period_us);
    freq_tenths = period_us > 0U ? (10000000UL / period_us) : 0U;
    valid = rc_capture_is_valid(pulse_us, period_us);
    sg90_angle_tenths =
        rc_pulse_to_signed_angle_tenths(pulse_us, RC_SG90_FULL_SCALE_TENTHS);
    n20_angle_tenths =
        rc_pulse_to_signed_angle_tenths(pulse_us, RC_N20_FULL_SCALE_TENTHS);
    sg90_abs_tenths = abs_i32_to_u32(sg90_angle_tenths);
    n20_abs_tenths = abs_i32_to_u32(n20_angle_tenths);

    printf("%lu,%u,%u,%lu.%lu,%u,%c%lu.%lu,%c%lu.%lu\r\n", frame_count,
           pulse_us, period_us, freq_tenths / 10U, freq_tenths % 10U, valid,
           sg90_angle_tenths < 0 ? '-' : '+', sg90_abs_tenths / 10U,
           sg90_abs_tenths % 10U, n20_angle_tenths < 0 ? '-' : '+',
           n20_abs_tenths / 10U, n20_abs_tenths % 10U);

    Delay_Ms(RC_INPUT_REPORT_INTERVAL_MS);
#elif TEST_MODE == TEST_MODE_SERVO_CONTROL
    uint32_t frame_count;
    uint16_t pulse_us;
    uint16_t period_us;
    uint16_t average;
    uint8_t signal_valid;
    int32_t measured_angle_tenths;
    int32_t error_tenths;
    uint32_t abs_error_tenths;
    uint16_t duty = 0;

    rc_capture_snapshot(&frame_count, &pulse_us, &period_us);
    if (frame_count != last_rc_frame_count) {
      last_rc_frame_count = frame_count;
      rc_stale_loops = 0;
    } else if (rc_stale_loops <
               (uint16_t)(RC_INPUT_TIMEOUT_MS / CONTROL_LOOP_INTERVAL_MS +
                          1U)) {
      rc_stale_loops++;
    }

    signal_valid = rc_capture_is_valid(pulse_us, period_us) &&
                   rc_stale_loops <= (uint16_t)(RC_INPUT_TIMEOUT_MS /
                                                CONTROL_LOOP_INTERVAL_MS);
    if (signal_valid != 0U) {
      int32_t command_angle_tenths = rc_pulse_to_signed_angle_tenths(
          pulse_us, SERVO_ANGLE_FULL_SCALE_TENTHS);
      target_angle_tenths =
          compensate_command_angle_tenths(command_angle_tenths);
    }

    average = adc_read_average(ADC_CONTROL_SAMPLES);
    measured_angle_tenths = adc_to_servo_angle_tenths(average);
    error_tenths = target_angle_tenths - measured_angle_tenths;
    abs_error_tenths = abs_i32_to_u32(error_tenths);

    if (signal_valid == 0U) {
      motor_pwm_coast();
      last_drive_direction = 0;
    } else if (abs_error_tenths <= CONTROL_POSITION_DEADBAND_TENTHS) {
#if CONTROL_HOLD_BRAKE_ENABLED
      motor_pwm_brake();
#else
      motor_pwm_coast();
#endif
      last_drive_direction = 0;
    } else {
      int8_t requested_direction = error_tenths > 0 ? 1 : -1;

      if (last_drive_direction != 0 &&
          requested_direction != last_drive_direction &&
          abs_error_tenths < CONTROL_REVERSE_DEADBAND_TENTHS) {
        motor_pwm_brake();
      } else {
        duty = control_duty_from_error(abs_error_tenths);
        if (requested_direction > 0) {
          motor_pwm_drive_toward_high(duty);
        } else {
          motor_pwm_drive_toward_low(duty);
        }
        last_drive_direction = requested_direction;
      }
    }

#if SERVO_CONTROL_TELEMETRY_ENABLE
    if (debug_elapsed_ms >= CONTROL_DEBUG_INTERVAL_MS) {
      uint32_t target_abs_tenths = abs_i32_to_u32(target_angle_tenths);
      uint32_t measured_abs_tenths = abs_i32_to_u32(measured_angle_tenths);
      uint32_t error_abs_tenths = abs_i32_to_u32(error_tenths);

      printf("%lu,%c%lu.%lu,%c%lu.%lu,%c%lu.%lu,%u,%u,%u\r\n", sample_index++,
             target_angle_tenths < 0 ? '-' : '+', target_abs_tenths / 10U,
             target_abs_tenths % 10U, measured_angle_tenths < 0 ? '-' : '+',
             measured_abs_tenths / 10U, measured_abs_tenths % 10U,
             error_tenths < 0 ? '-' : '+', error_abs_tenths / 10U,
             error_abs_tenths % 10U, duty, pulse_us, signal_valid);
      debug_elapsed_ms = 0;
    }

    debug_elapsed_ms += CONTROL_LOOP_INTERVAL_MS;
#endif
    Delay_Ms(CONTROL_LOOP_INTERVAL_MS);
#else
    uint16_t raw = adc_read_raw();
    uint16_t average = adc_read_average(ADC_AVERAGE_SAMPLES);
    uint32_t millivolts =
        ((uint32_t)average * ADC_REFERENCE_MV + (ADC_FULL_SCALE_COUNTS / 2U)) /
        ADC_FULL_SCALE_COUNTS;
    uint32_t percent_tenths =
        ((uint32_t)average * 1000U + (ADC_FULL_SCALE_COUNTS / 2U)) /
        ADC_FULL_SCALE_COUNTS;
    uint32_t angle_tenths = adc_to_pot_angle_tenths(average);

#if TEST_MODE == TEST_MODE_MOTOR_SWEEP
    if (sweep_direction == SWEEP_TOWARD_HIGH) {
      if (angle_tenths < sweep_midpoint_tenths) {
        endpoint_armed = 1;
      }

      if (endpoint_armed && angle_tenths >= (SWEEP_HIGH_TARGET_TENTHS -
                                             SWEEP_TARGET_TOLERANCE_TENTHS)) {
        motor_pwm_brake();
        Delay_Ms(MOTOR_REVERSE_BRAKE_MS);
        motor_pwm_coast();
        Delay_Ms(SWEEP_ENDPOINT_SETTLE_MS);
        sweep_direction = SWEEP_TOWARD_LOW;
        endpoint_armed = 0;
        direction_changes++;
        motor_pwm_drive_toward_low(MOTOR_PWM_DUTY_MAX);
      } else {
        motor_pwm_drive_toward_high(MOTOR_PWM_DUTY_MAX);
      }
    } else {
      if (angle_tenths > sweep_midpoint_tenths) {
        endpoint_armed = 1;
      }

      if (endpoint_armed && angle_tenths <= (SWEEP_LOW_TARGET_TENTHS +
                                             SWEEP_TARGET_TOLERANCE_TENTHS)) {
        motor_pwm_brake();
        Delay_Ms(MOTOR_REVERSE_BRAKE_MS);
        motor_pwm_coast();
        Delay_Ms(SWEEP_ENDPOINT_SETTLE_MS);
        sweep_direction = SWEEP_TOWARD_HIGH;
        endpoint_armed = 0;
        direction_changes++;
        motor_pwm_drive_toward_high(MOTOR_PWM_DUTY_MAX);
      } else {
        motor_pwm_drive_toward_low(MOTOR_PWM_DUTY_MAX);
      }
    }
#endif

    printf("%lu,%u,%u,%lu,%lu.%lu,%lu.%lu", sample_index++, raw, average,
           millivolts, percent_tenths / 10U, percent_tenths % 10U,
           angle_tenths / 10U, angle_tenths % 10U);
#if TEST_MODE == TEST_MODE_MOTOR_SWEEP
    printf(",%lu", direction_changes);
#else
    printf(",0");
#endif
    printf("\r\n");

    Delay_Ms(ADC_UPDATE_INTERVAL_MS);
#endif
  }

  return 0;
}

void NMI_Handler(void) {}
void HardFault_Handler(void) {
  while (1) {
  }
}

#if MODE_USES_RC_INPUT
void TIM1_CC_IRQHandler(void) {
  if (TIM_GetITStatus(TIM1, TIM_IT_CC4) != RESET) {
    uint16_t capture_us = TIM_GetCapture4(TIM1);
    TIM_ClearITPendingBit(TIM1, TIM_IT_CC4);

    if (rc_waiting_for_falling_edge == 0U) {
      if (rc_have_rising_edge != 0U) {
        rc_period_us = timer_delta_u16(capture_us, rc_last_rising_capture_us);
      }

      rc_last_rising_capture_us = capture_us;
      rc_have_rising_edge = 1U;
      rc_waiting_for_falling_edge = 1U;
      TIM_OC4PolarityConfig(TIM1, TIM_ICPolarity_Falling);
    } else {
      rc_pulse_width_us =
          timer_delta_u16(capture_us, rc_last_rising_capture_us);
      rc_frame_count++;
      rc_waiting_for_falling_edge = 0U;
      TIM_OC4PolarityConfig(TIM1, TIM_ICPolarity_Rising);
    }
  }
}
#endif
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

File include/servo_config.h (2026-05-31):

#ifndef SERVO_CONFIG_H
#define SERVO_CONFIG_H

#include <ch32v00x.h>

/*
 * User configuration for the N20 servo firmware.
 *
 * Angle values ending in _TENTHS are in 0.1 degree units:
 *   1500 = 150.0 degrees
 *   12   = 1.2 degrees
 */

/* ADC input GPIO port for the potentiometer wiper. */
#ifndef ADC_INPUT_GPIO_PORT
#define ADC_INPUT_GPIO_PORT GPIOA
#endif

/* ADC input GPIO pin for the potentiometer wiper. PA2 is ADC channel A0. */
#ifndef ADC_INPUT_GPIO_PIN
#define ADC_INPUT_GPIO_PIN GPIO_Pin_2
#endif

/* ADC regular channel matching ADC_INPUT_GPIO_PIN. PA2 uses ADC_Channel_0. */
#ifndef ADC_INPUT_CHANNEL
#define ADC_INPUT_CHANNEL ADC_Channel_0
#endif

/* Number of ADC samples used for diagnostic averaging. */
#ifndef ADC_AVERAGE_SAMPLES
#define ADC_AVERAGE_SAMPLES 16U
#endif

/* Number of ADC samples used per closed-loop control update. */
#ifndef ADC_CONTROL_SAMPLES
#define ADC_CONTROL_SAMPLES 4U
#endif

/* Maximum 10-bit ADC count from the CH32V003 ADC. */
#ifndef ADC_FULL_SCALE_COUNTS
#define ADC_FULL_SCALE_COUNTS 1023U
#endif

/* ADC reference voltage in millivolts for debug output calculations. */
#ifndef ADC_REFERENCE_MV
#define ADC_REFERENCE_MV 5000U
#endif

/* Delay between ADC-only or motor-sweep debug rows. */
#ifndef ADC_UPDATE_INTERVAL_MS
#define ADC_UPDATE_INTERVAL_MS 10U
#endif

/* Full potentiometer travel used by ADC-only angle display. */
#ifndef ANGLE_FULL_SCALE_DEGREES
#define ANGLE_FULL_SCALE_DEGREES 330U
#endif

/* UART baud rate for printf when SDI_PRINT is disabled. */
#ifndef UART_BAUD_RATE
#define UART_BAUD_RATE 921600U
#endif

/* ADC-only mode: read the potentiometer and print ADC/angle data. */
#define TEST_MODE_ADC_ONLY 0U

/* Motor sweep mode: drive between configured sweep endpoints. */
#define TEST_MODE_MOTOR_SWEEP 1U

/* Backward-compatible name for the motor sweep test mode. */
#define TEST_MODE_MOTOR_AND_ADC TEST_MODE_MOTOR_SWEEP

/* RC input-capture mode: measure incoming 50 Hz servo PWM only. */
#define TEST_MODE_RC_INPUT_CAPTURE 2U

/* Closed-loop servo mode: capture RC input and control motor position. */
#define TEST_MODE_SERVO_CONTROL 3U

/* Default firmware mode when platformio.ini does not override TEST_MODE. */
#ifndef TEST_MODE
#define TEST_MODE TEST_MODE_SERVO_CONTROL
#endif

/* Enable CSV telemetry in closed-loop mode. Keep off for lowest loop jitter. */
#ifndef SERVO_CONTROL_TELEMETRY_ENABLE
#define SERVO_CONTROL_TELEMETRY_ENABLE 0
#endif

/* GPIO port for the incoming 50 Hz RC servo PWM signal. */
#ifndef RC_INPUT_GPIO_PORT
#define RC_INPUT_GPIO_PORT GPIOC
#endif

/* GPIO pin for the incoming 50 Hz RC servo PWM signal. PC4 uses TIM1_CH4. */
#ifndef RC_INPUT_GPIO_PIN
#define RC_INPUT_GPIO_PIN GPIO_Pin_4
#endif

/* Pulse width mapped to full negative command. */
#ifndef RC_INPUT_MIN_US
#define RC_INPUT_MIN_US 1000U
#endif

/* Pulse width mapped to center command. */
#ifndef RC_INPUT_CENTER_US
#define RC_INPUT_CENTER_US 1500U
#endif

/* Pulse width mapped to full positive command. */
#ifndef RC_INPUT_MAX_US
#define RC_INPUT_MAX_US 2000U
#endif

/* Lowest pulse width accepted as a valid input-capture signal. */
#ifndef RC_INPUT_VALID_MIN_US
#define RC_INPUT_VALID_MIN_US 750U
#endif

/* Highest pulse width accepted as a valid input-capture signal. */
#ifndef RC_INPUT_VALID_MAX_US
#define RC_INPUT_VALID_MAX_US 2250U
#endif

/* Lowest accepted RC frame period. 15000 us is about 66 Hz. */
#ifndef RC_INPUT_PERIOD_VALID_MIN_US
#define RC_INPUT_PERIOD_VALID_MIN_US 15000U
#endif

/* Highest accepted RC frame period. 25000 us is 40 Hz. */
#ifndef RC_INPUT_PERIOD_VALID_MAX_US
#define RC_INPUT_PERIOD_VALID_MAX_US 25000U
#endif

/* Delay between rows in RC input-capture diagnostic mode. */
#ifndef RC_INPUT_REPORT_INTERVAL_MS
#define RC_INPUT_REPORT_INTERVAL_MS 100U
#endif

/* Time without a fresh RC frame before closed-loop mode coasts the motor. */
#ifndef RC_INPUT_TIMEOUT_MS
#define RC_INPUT_TIMEOUT_MS 100U
#endif

/* Reference SG90-style command range shown in input-capture diagnostics. */
#ifndef RC_SG90_FULL_SCALE_TENTHS
#define RC_SG90_FULL_SCALE_TENTHS 900
#endif

/* N20 servo command range shown in input-capture diagnostics. */
#ifndef RC_N20_FULL_SCALE_TENTHS
#define RC_N20_FULL_SCALE_TENTHS 1500
#endif

/* Absolute measured servo range used by the feedback potentiometer mapping. */
#ifndef SERVO_ANGLE_FULL_SCALE_TENTHS
#define SERVO_ANGLE_FULL_SCALE_TENTHS 1600
#endif

/* ADC count measured at the negative mechanical endpoint. */
#ifndef POT_ADC_AT_NEG160
#define POT_ADC_AT_NEG160 47U
#endif

/* ADC count measured at the center position. */
#ifndef POT_ADC_AT_CENTER
#define POT_ADC_AT_CENTER 512U
#endif

/* ADC count measured at the positive mechanical endpoint. */
#ifndef POT_ADC_AT_POS160
#define POT_ADC_AT_POS160 977U
#endif

/* Command gain trim in permille. 1000 means no scale correction. */
#ifndef SERVO_COMMAND_GAIN_PERMILLE
#define SERVO_COMMAND_GAIN_PERMILLE 1062
#endif
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

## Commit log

2026-05-31 modified: .gitignore new file: include/servo_config.h modified: platformio.ini modified: src/main.c new file: tools/README.md new file: tools/serial_dashboard.py
2026-05-31 modified: tools/README.md new file: tools/servo_configurator.py
2026-06-03 new file: README.md new file: images/CAD.jpg new file: images/angle_sensor.jpg new file: images/behind.jpg new file: images/bottom_populated.jpg new file: images/front.jpg new file: images/iso_0.jpg 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
2026-06-05 modified: README.md new file: cad/Adapter collet.step new file: "cad/Body and cover (\320\2242).step" new file: cad/Servo Assembly.step new file: images/compare.jpg new file: images/placeholder.jpg n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
    [Adapter collet.step, Body and cover (Д2).step, Servo Assembly.step]

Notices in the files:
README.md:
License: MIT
